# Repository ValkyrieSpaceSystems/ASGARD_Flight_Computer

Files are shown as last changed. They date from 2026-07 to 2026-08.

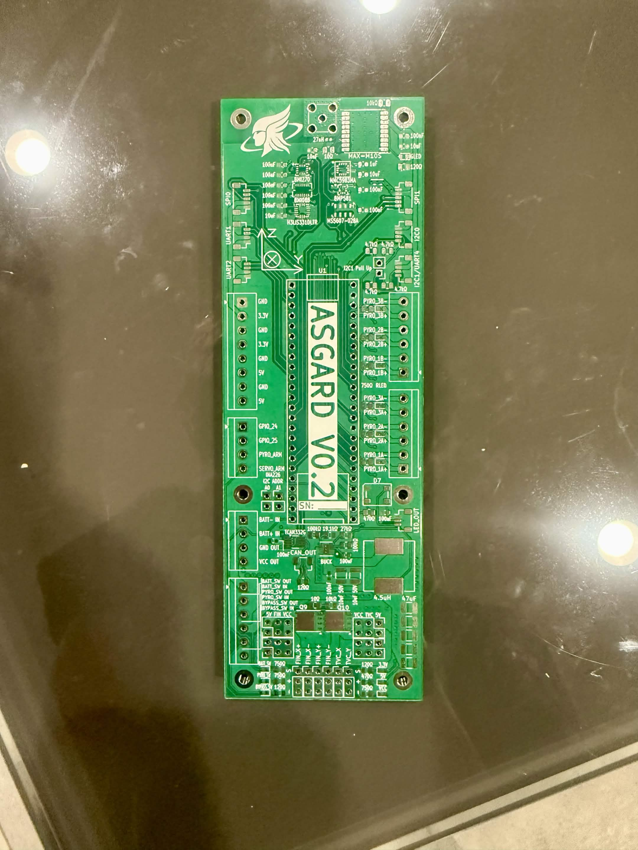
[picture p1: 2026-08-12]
V0.2 Front Picture (Not Assembled).png

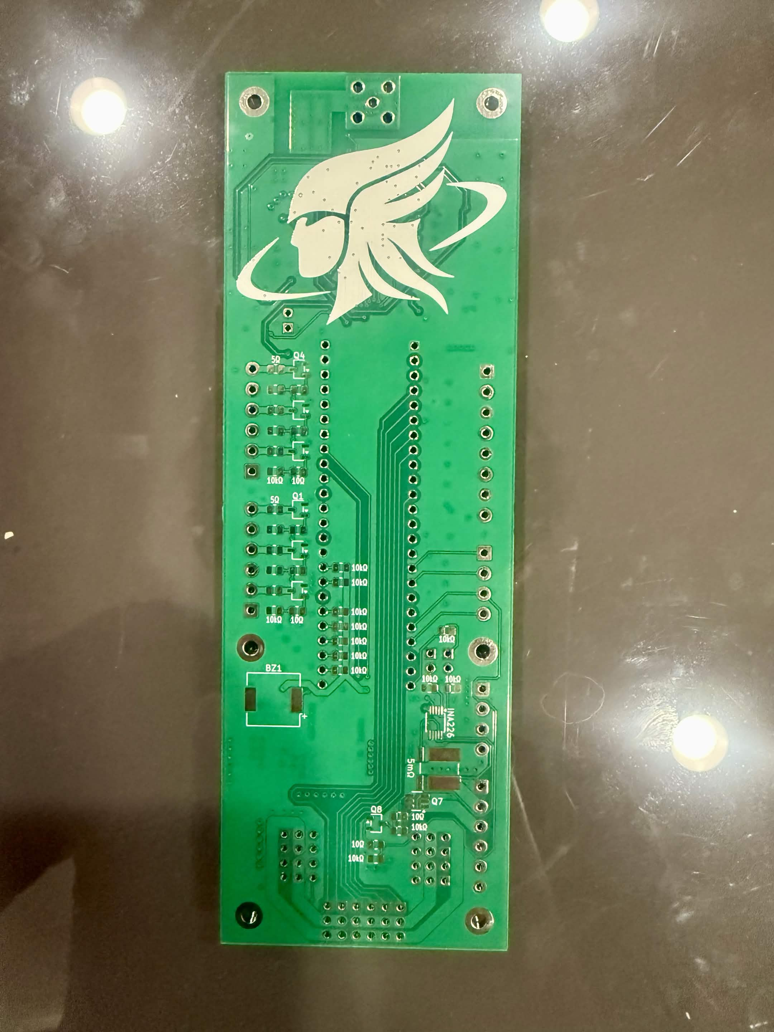
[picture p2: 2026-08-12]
V0.2 Back Picture (Not Assembled).png

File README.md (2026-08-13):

# Asgard Flight Computer

An open-source high power rocketry flight computer designed for long-term affordability through flexibility, modularity, and expandability. Designed to fly with [ODIN flight software](https://github.com/ValkyrieSpaceSystems/ODIN_Flight_Software) and communicate with the [Midgard ground station](https://github.com/ValkyrieSpaceSystems/MIDGARD_Ground_Control) over the [BIFROST protocol](https://github.com/ValkyrieSpaceSystems/BIFROST_Communications_Protocol).

---

## Sensors

| Component | Part | Interface |
|---|---|---|
| Low-altitude barometer | BMP581 | SPI |
| High-altitude barometer *(optional)* | MS5607 | SPI |
| Low-g IMU | BMI270 | SPI |
| Mid-g IMU | BMI088 | SPI |
| High-g accelerometer | H3LIS331DLTR | SPI |
| Magnetometer | MMC5983MA | SPI |
| GNSS | MAX-M10S | UART |
| Current monitor | INA226 | I2C |

---

## Pyrotechnics

3 independent events, 2 channels each (6 total). High-side arming via external switch keeps all channels unpowered until deliberately armed. Each channel has its own independent low-side MOSFET.

---

## Servo Control

6 outputs — a 4-channel group for fin deflection and a 2-channel group for thrust vector control. Each group is independently configurable via jumper to run from battery or regulated 5V.

---

## Communications

Interface agnostic — any physical transport (XBee, ELRS, RS-485, Bluetooth, CAN, USB, etc.) can carry BIFROST traffic with no firmware changes. A bypass switch port enables autonomous operation if ground station comms are unavailable.

---

## Expansion

2× SPI, 3× UART, 2× I2C, 1× CAN expansion ports, plus 2 GPIO breakout pins. Pyro arm and servo arm signals are also broken out for auxiliary boards.

**Current expansion boards:** RS-485, GPIO breakout

**Planned:** camera module, extra sensors, payload, multi-stage, Bluetooth/WiFi, high-power servos, pyro expansion

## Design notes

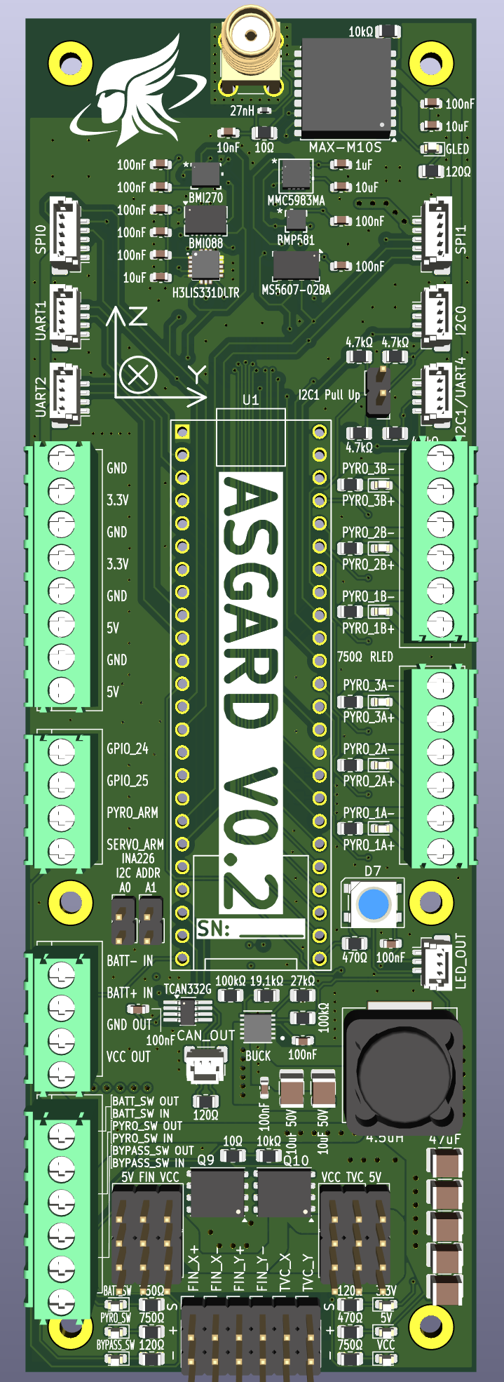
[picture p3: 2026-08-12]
V0.2 Front Render.png

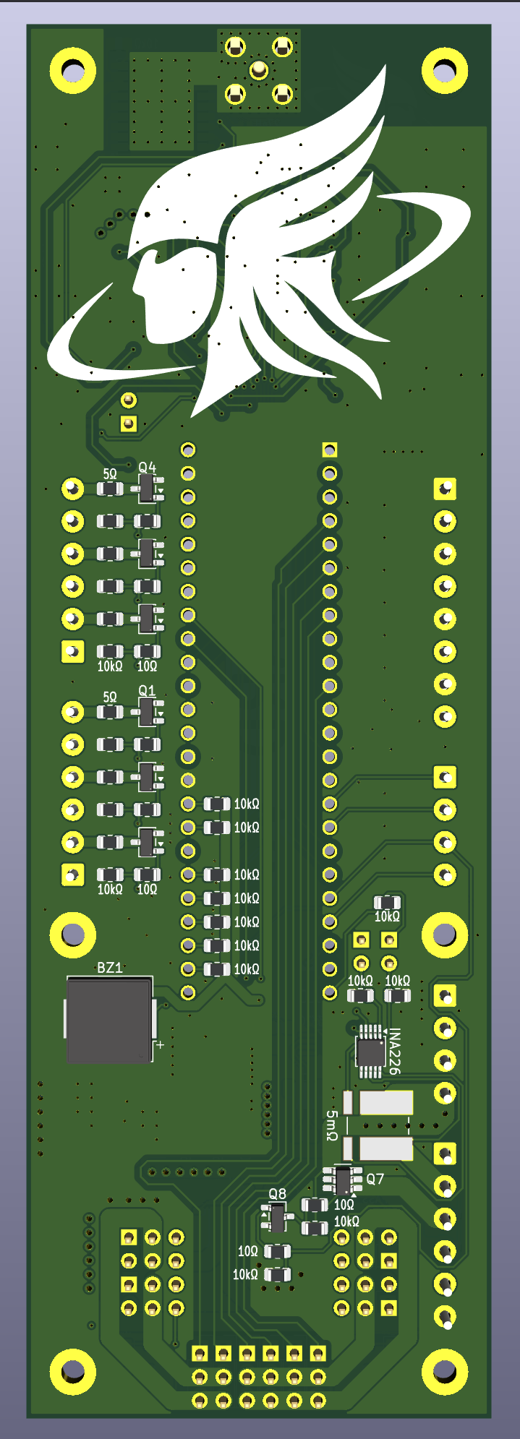
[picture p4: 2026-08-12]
V0.2 Back Render.png

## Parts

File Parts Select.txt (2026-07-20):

Low Altitude Barometer BMP581 (1)
	https://www.digikey.com/en/products/detail/bosch-sensortec/BMP581/16036134
	https://www.adafruit.com/product/6407
	https://www.sparkfun.com/sparkfun-micro-pressure-sensor-bmp581-qwiic.html
	https://github.com/adafruit/Adafruit_BMP5xx
	
High Altitude Barometer MS560702BA03-50 (1)
	https://www.digikey.com/en/products/detail/te-connectivity-measurement-specialties/MS560702BA03-50/4700931
	https://github.com/UravuLabs/MS5607

Low-G IMU BMI270 (1)
	https://www.digikey.com/en/products/detail/bosch-sensortec/BMI270/9974486
	https://www.sparkfun.com/sparkfun-6dof-imu-breakout-bmi270-qwiic.html
	https://github.com/sparkfun/SparkFun_BMI270_Arduino_Library

Mid-G IMU BMI088 (1)
	https://www.digikey.com/en/products/detail/bosch-sensortec/BMI088/8634936
	https://www.mouser.com/ProductDetail/Bosch-Sensortec/BMI088?qs=f9yNj16SXrIMFspTV6RB6Q%3D%3D
	https://github.com/AeroStrike/BMI088-Breakout-Board
	https://github.com/bolderflight/bmi088-arduino

High-G Accelerometer H3LIS331DLTR (1)
	https://www.digikey.com/en/products/detail/stmicroelectronics/H3LIS331DLTR/4311633
	https://www.adafruit.com/product/4627
	https://www.sparkfun.com/sparkfun-triple-axis-accelerometer-breakout-h3lis331dl.html
	https://github.com/sparkfun/SparkFun_LIS331_Arduino_Library

Magnetometer MMC5983MA (1)
	https://www.digikey.com/en/products/detail/memsic-inc/MMC5983MA/10452795
	https://www.sparkfun.com/sparkfun-micro-magnetometer-mmc5983ma-qwiic.html
	https://github.com/sparkfun/SparkFun_MMC5983MA_Magnetometer_Arduino_Library

Radio XBEE-PRO 900HP (1)
	https://www.tinyosshop.com/index.php?route=product/product&product_id=358
	https://www.digikey.com/en/products/detail/digi/XBP9B-DMST-002/3594157
	https://docs.digi.com//resources/documentation/digidocs/pdfs/90002474.pdf
	https://how2electronics.com/how-to-set-up-interface-xbee-module-with-arduino-tx-rx/
	https://learn.sparkfun.com/tutorials/exploring-xbees-and-xctu/all
	https://cse.google.com/cse?cx=008830049033802121810%3Azgsyidwem5w&q=xbee
	
Radio ELRS (1)

GNSS MAX-M10S-00B (1)
	https://www.digikey.com/en/products/detail/u-blox/MAX-M10S-00B/15712909
	https://www.sparkfun.com/sparkfun-gnss-receiver-breakout-max-m10s-qwiic.html
	https://github.com/sparkfun/SparkFun_u-blox_GNSS_v3
	https://content.u-blox.com/sites/default/files/MAX-M10S_IntegrationManual_UBX-20053088.pdf

Flash W25Q128JVSIQ TR (1)
	https://www.digikey.com/en/products/detail/winbond-electronics/W25Q128JVSIQ-TR/5803944
	https://www.hackster.io/news/adding-more-ram-and-flash-to-the-teensy-4-1-89e527855502
	https://github.com/PaulStoffregen/LittleFS
	
CANbus Transceiver TCAN332GDCNR (1)
	https://www.digikey.com/en/products/detail/texas-instruments/TCAN332GDCNR/6572320
	https://github.com/tonton81/FlexCAN_T4
	
5V Buck Converter LMR51460FSQDRRRQ1 (1)
	https://www.digikey.com/en/products/detail/texas-instruments/LMR51460FSQDRRRQ1/25318369
	
Current Monitor INA226AIDGSR (1)
	https://www.digikey.com/en/products/detail/texas-instruments/INA226AIDGSR/2687236
	https://github.com/RobTillaart/INA226

P-Channel MOSFET 6.9A SQ3419CEV-T1_GE3 (1)
	https://www.digikey.com/en/products/detail/vishay-siliconix/SQ3419CEV-T1-GE3/22080316
	https://www.adafruit.com/product/1794
N-Channel MOSFET 5A SI2318A-TP (6)
	https://www.digikey.com/en/products/detail/mcc-micro-commercial-components/SI2318A-TP/965103 mm5963
	https://www.adafruit.com/product/355
N-Channel MOSFET 17A BSC059N04LS6ATMA1 (2)
	https://www.digikey.com/en/products/detail/infineon-technologies/BSC059N04LS6ATMA1/9829538
NPN Transistor 2N3904 (1)
	https://www.digikey.com/en/products/detail/diotec-semiconductor/2N3904/13164701
	https://www.sparkfun.com/bag-o-transistors.html

 - Battery
 	-

Fingertech Mini Switch (3)
	https://www.csrocketry.com/electronics/altus-metrum/fingertech-mini-switch.html

E-Match Starter Kit
	https://www.apogeerockets.com/Rocket-Motors/Motor-Starters/E-match-Starter-Kit

SMA Connector (1)
	https://www.digikey.com/en/products/detail/adam-tech/RF2-04A-T-00-50-G/9830588

Battery Plugs XT60 (1M & 1F) FIT0587 (1)
	https://www.digikey.com/en/products/detail/dfrobot/FIT0587/9559256
	
1x2 Screw Terminal OSTTE020104 (17)
	https://www.digikey.com/en/products/detail/on-shore-technology-inc/OSTTE020104/2351816
	
Pin Headers (50M) (48F)
	2x3M (4) (Servo PWR/GND Select)
	1x3M (6) (Servos)
	1x2M (4) (I2C Jumpers)
	1x24F (2) (Teensy)
Pin Jumpers 0015381026 (11 max)
	https://www.digikey.com/en/products/detail/molex/0015381026/315124

JST SH 2 pin Connectors (1)
	https://www.digikey.com/en/products/detail/jst-sales-america-inc/BM02B-SRSS-TB/926694
JST SH 3 pin Connectors (1)
	https://www.digikey.com/en/products/detail/jst-sales-america-inc/BM03B-SRSS-TB/926695
JST SH 4 pin Connectors (10 pack) (4)
	https://www.adafruit.com/product/4328
	https://www.digikey.com/en/products/detail/jst-sales-america-inc/BM04B-SRSS-TB/926696
JST SH 5 pin Connectors (2)
	https://www.digikey.com/en/products/detail/jst-sales-america-inc/BM05B-SRSS-TB/926697
JST SH 8 pin Connectors (0)
	https://www.digikey.com/en/products/detail/jst-sales-america-inc/BM08B-SRSS-TB/926700

Buzzer CPT-9019A-SMT-TR (1)
	https://www.digikey.com/en/products/detail/same-sky-formerly-cui-devices/CPT-9019A-SMT-TR/19105220
NEOPIXEL (1)
	https://www.digikey.com/en/products/detail/w%C3%BCrth-elektronik/1315050930002/22677876
	https://www.adafruit.com/product/1655
	https://github.com/adafruit/Adafruit_NeoPixel
Red Indicator LEDs LTST-C191KRKT (6)
	https://www.digikey.com/en/products/detail/liteon/LTST-C191KRKT/386837
Green Indicator LEDs LTST-C191KGKT (1)
	https://www.digikey.com/en/products/detail/liteon/LTST-C191KGKT/386835
Orange Indicator LEDs LTST-C191KFKT (6)
	https://www.digikey.com/en/products/detail/liteon/LTST-C191KFKT/386833

5mΩ Shunt Resistor WSLP27265L000FEA (1)
	https://www.digikey.com/en/products/detail/vishay-dale/WSLP27265L000FEA/9751106
5Ω Resisotr ERJ-P06J5R1V (6)
	https://www.digikey.com/en/products/detail/panasonic-industry/ERJ-P06J5R1V/9812037
10Ω Resistor ERJ-P06J100V (10)
	https://www.digikey.com/en/products/detail/panasonic-industry/ERJ-P06J100V/525195
120Ω Resistor ERJ-P06J121V (4)
	https://www.digikey.com/en/products/detail/panasonic-industry/ERJ-P06J121V/525207
470Ω Resistor ERJ-P06J471V (2)
	https://www.digikey.com/en/products/detail/panasonic-industry/ERJ-P06J471V/525276
750Ω Resistor ERJ-P06J751V (9)
	https://www.digikey.com/en/products/detail/panasonic-industry/ERJ-P06J751V/525301
1kΩ Resistor ERJ-P06J102V (0)
	https://www.digikey.com/en/products/detail/panasonic-industry/ERJ-P06J102V/525197
4.7kΩ Resistor ERJ-P06J472V (4)
	https://www.digikey.com/en/products/detail/panasonic-industry/ERJ-P06J472V/525277
10kΩ Resistor ERJ-P06J103V (20)
	https://www.digikey.com/en/products/detail/panasonic-industry/ERJ-P06J103V/525198
19.1kΩ Resistor CRCW080519K1FKEAHP (1)
	https://www.digikey.com/en/products/detail/vishay-dale/CRCW080519K1FKEAHP/2227102
27kΩ Resistor ERJ-P06J273V (1)
	https://www.digikey.com/en/products/detail/panasonic-industry/ERJ-P06J273V/525249
100kΩ Resistor ERJ-P06J104V (2)
	https://www.digikey.com/en/products/detail/panasonic-industry/ERJ-P06J104V/525199

47pF 50V Capacitor CL10C470JB8NNNC (0)
	https://www.digikey.com/en/products/detail/samsung-electro-mechanics/CL10C470JB8NNNC/3886695
10nF 50V Capacitor C0603C103K5RACTU (1)
	https://www.digikey.com/en/products/detail/kemet/C0603C103K5RACTU/411090
100nF 50V Capacitor C1608X5R1H104K080AA (12)
	https://www.digikey.com/en/products/detail/tdk/C1608X5R1H104K080AA/2732891
1uF 16V Capacitor C0603C105K4RACTU (1)
	https://www.digikey.com/en/products/detail/kemet/C0603C105K4RACTU/2199788
10uF 25V Capacitor CL10A106MA8NRNC (3)
	https://www.digikey.com/en/products/detail/samsung-electro-mechanics/CL10A106MA8NRNC/3887527
10uF 50V Capapacitor C3225X7R1H106M250AC (2)
	https://www.digikey.com/en/products/detail/tdk/C3225X7R1H106M250AC/3952169
10uF 50V Polarized Capacitor 106CKH050MSA (0)
	https://www.digikey.com/en/products/detail/cornell-dubilier-knowles/106CKH050MSA/22188172
22uF 10V Capapacitor MSASL219LB5226MTNA01 (0)
	https://www.digikey.com/en/products/detail/taiyo-yuden/msasl219lb5226mtna01/16660989
47uF 16V Capacitor GRM32EC81C476KE15L (5)
	https://www.digikey.com/en/products/detail/murata-electronics/GRM32EC81C476KE15L/5027615

4.5uH Inductor SRR1208-4R5ML (1)
	https://www.digikey.com/en/products/detail/bourns-inc/SRR1208-4R5ML/2352894
27nH Inductor LQG15HS27NJ02D (1)
	https://www.digikey.com/en/products/detail/murata-electronics/LQG15HS27NJ02D/662877

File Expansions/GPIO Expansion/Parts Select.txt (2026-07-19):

GPIO Expander MCP23017T-E/SO (1)
	https://www.digikey.com/en/products/detail/microchip-technology/MCP23017T-E-SO/964184
	https://www.adafruit.com/product/5346
	https://github.com/adafruit/Adafruit-MCP23017-Arduino-Library

1x2 Screw Terminal OSTTE020104 (8)
	https://www.digikey.com/en/products/detail/on-shore-technology-inc/OSTTE020104/2351816
	
Pin Headers (6M)
	1x2M (3)
Pin Jumpers 0015381026 (3 max)
	https://www.digikey.com/en/products/detail/molex/0015381026/315124

JST SH 4 pin Connectors (10 pack) (2)
	https://www.adafruit.com/product/4328
	https://www.digikey.com/en/products/detail/jst-sales-america-inc/BM04B-SRSS-TB/926696

10kΩ Resistor ERJ-P06J103V (4)
	https://www.digikey.com/en/products/detail/panasonic-industry/ERJ-P06J103V/525198

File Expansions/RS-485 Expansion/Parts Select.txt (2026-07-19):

RS-485 Transceiver THVD1420DRLR (1)
	https://www.digikey.com/en/products/detail/texas-instruments/THVD1420DRLR/15856992

1x2 Screw Terminal OSTTE020104 (3)
	https://www.digikey.com/en/products/detail/on-shore-technology-inc/OSTTE020104/2351816
	
JST SH 4 pin Connectors (10 pack) (1)
	https://www.adafruit.com/product/4328
	https://www.digikey.com/en/products/detail/jst-sales-america-inc/BM04B-SRSS-TB/926696

RJ45 Connector (1)
	https://www.digikey.com/en/products/detail/abracon-llc/ARJM11D7-009-NN-EW2/7675212

120Ω Resistor ERJ-P06J121V (1)
	https://www.digikey.com/en/products/detail/panasonic-industry/ERJ-P06J121V/525207
750Ω Resistor ERJ-P06J751V (2)
	https://www.digikey.com/en/products/detail/panasonic-industry/ERJ-P06J751V/525301
10kΩ Resistor ERJ-P06J103V (2)
	https://www.digikey.com/en/products/detail/panasonic-industry/ERJ-P06J103V/525198

100nF 50V Capacitor C1608X5R1H104K080AA (2)
	https://www.digikey.com/en/products/detail/tdk/C1608X5R1H104K080AA/2732891

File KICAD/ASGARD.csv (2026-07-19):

Reference | Qty | Value | DNP | Exclude from BOM | Exclude from Board | Footprint | Datasheet
C1,C2 | 2 | 10uF 50V |  |  |  | Capacitor_SMD:C_1210_3225Metric
C3,C4,C10,C11,C12,C13,C14,C18,C19 | 9 | 100nF |  |  |  | Capacitor_SMD:C_0603_1608Metric
C5,C6,C7,C8,C9 | 5 | 47uF |  |  |  | Capacitor_SMD:C_1210_3225Metric
C15 | 1 | 10uF |  |  |  | Capacitor_THT:CP_Radial_D5.0mm_P2.00mm
C16 | 1 | 1uF |  |  |  | Capacitor_SMD:C_0603_1608Metric
C17,C20 | 2 | 10uF 25V |  |  |  | Capacitor_SMD:C_0603_1608Metric
C21 | 1 | 10nF |  |  |  | Capacitor_SMD:C_0603_1608Metric
C22 | 1 | 47pF |  |  |  | Capacitor_SMD:C_0603_1608Metric
D1,D2,D3,D4,D5,D6 | 6 | RLED |  |  |  | LED_SMD:LED_0603_1608Metric
D7 | 1 | NEOPIXEL |  |  |  | LED_SMD:LED_Inolux_IN-PI554FCH_PLCC4_5.0x5.0mm_P3.2mm | http://www.inolux-corp.com/datasheet/SMDLED/Addressable%20LED/IN-PI554FCH.pdf
D8,D9,D10,D11,D20 | 5 | GLED |  |  |  | LED_SMD:LED_0603_1608Metric
D17,D18,D19 | 3 | OLED |  |  |  | LED_SMD:LED_0603_1608Metric
J1 | 1 | BATT_TERM |  |  |  | TerminalBlock_4Ucon:TerminalBlock_4Ucon_1x04_P3.50mm_Horizontal
J2 | 1 | ARMING/GPIO |  |  |  | TerminalBlock_4Ucon:TerminalBlock_4Ucon_1x04_P3.50mm_Horizontal
J3 | 1 | PYRO_TERM_A |  |  |  | TerminalBlock_4Ucon:TerminalBlock_4Ucon_1x06_P3.50mm_Horizontal
J4 | 1 | PYRO_TERM_B |  |  |  | TerminalBlock_4Ucon:TerminalBlock_4Ucon_1x06_P3.50mm_Horizontal
J7 | 1 | SPI0 |  |  |  | Connector_JST:JST_SH_BM05B-SRSS-TB_1x05-1MP_P1.00mm_Vertical
J8 | 1 | SPI1 |  |  |  | Connector_JST:JST_SH_BM05B-SRSS-TB_1x05-1MP_P1.00mm_Vertical
J9 | 1 | CAN_OUT |  |  |  | Connector_JST:JST_SH_BM02B-SRSS-TB_1x02-1MP_P1.00mm_Vertical
J11 | 1 | SWITCH_TERM |  |  |  | TerminalBlock_4Ucon:TerminalBlock_4Ucon_1x06_P3.50mm_Horizontal
J12 | 1 | LED_OUT |  |  |  | Connector_JST:JST_SH_BM03B-SRSS-TB_1x03-1MP_P1.00mm_Vertical
J13 | 1 | UART1 |  |  |  | Connector_JST:JST_SH_BM04B-SRSS-TB_1x04-1MP_P1.00mm_Vertical
J14 | 1 | UART2 |  |  |  | Connector_JST:JST_SH_BM04B-SRSS-TB_1x04-1MP_P1.00mm_Vertical
J15 | 1 | CAN_IN |  |  |  | Connector_JST:JST_SH_BM02B-SRSS-TB_1x02-1MP_P1.00mm_Vertical
J16 | 1 | UART3 |  |  |  | Connector_JST:JST_SH_BM04B-SRSS-TB_1x04-1MP_P1.00mm_Vertical
J17 | 1 | SMA |  |  |  | Connector_Coaxial:SMA_Amphenol_132134-11_Vertical
J18 | 1 | I2C0 |  |  |  | Connector_JST:JST_SH_BM04B-SRSS-TB_1x04-1MP_P1.00mm_Vertical
J19 | 1 | 5V |  |  |  | TerminalBlock_4Ucon:TerminalBlock_4Ucon_1x04_P3.50mm_Horizontal
J21 | 1 | I2C1/UART4 |  |  |  | Connector_JST:JST_SH_BM04B-SRSS-TB_1x04-1MP_P1.00mm_Vertical
J22 | 1 | 3.3V |  |  |  | TerminalBlock_4Ucon:TerminalBlock_4Ucon_1x04_P3.50mm_Horizontal
J23 | 1 | UART5 |  |  |  | Connector_JST:JST_SH_BM04B-SRSS-TB_1x04-1MP_P1.00mm_Vertical
JP3 | 1 | I2C1 Pull Up |  |  |  | Connector_PinHeader_2.54mm:PinHeader_1x02_P2.54mm_Vertical
JP4,JP5 | 2 | Jumper_2_Open |  |  |  | Connector_PinHeader_2.54mm:PinHeader_1x02_P2.54mm_Vertical
L1 | 1 | 4.5uH |  |  |  | SRR1208-120ML:IND_SRR1208-120ML
L2 | 1 | 27nH |  |  |  | Inductor_SMD:L_0402_1005Metric
M1 | 1 | FIN_X+ |  |  |  | Connector_PinHeader_2.54mm:PinHeader_1x03_P2.54mm_Vertical | http://forums.parallax.com/uploads/attachments/46831/74481.png
M2 | 1 | FIN_X- |  |  |  | Connector_PinHeader_2.54mm:PinHeader_1x03_P2.54mm_Vertical | http://forums.parallax.com/uploads/attachments/46831/74481.png
M3 | 1 | FIN_Y+ |  |  |  | Connector_PinHeader_2.54mm:PinHeader_1x03_P2.54mm_Vertical | http://forums.parallax.com/uploads/attachments/46831/74481.png
M4 | 1 | FIN_Y- |  |  |  | Connector_PinHeader_2.54mm:PinHeader_1x03_P2.54mm_Vertical | http://forums.parallax.com/uploads/attachments/46831/74481.png
M5 | 1 | TVC_X |  |  |  | Connector_PinHeader_2.54mm:PinHeader_1x03_P2.54mm_Vertical | http://forums.parallax.com/uploads/attachments/46831/74481.png
M6 | 1 | TVC_Y |  |  |  | Connector_PinHeader_2.54mm:PinHeader_1x03_P2.54mm_Vertical | http://forums.parallax.com/uploads/attachments/46831/74481.png
Q1 | 1 | DROGUE_MOSFET_A |  |  |  | Package_TO_SOT_SMD:SOT-23-3
Q2 | 1 | MAIN_MOSFET_A |  |  |  | Package_TO_SOT_SMD:SOT-23-3
Q3 | 1 | MOTOR_MOSFET_A |  |  |  | Package_TO_SOT_SMD:SOT-23-3
Q4 | 1 | DROGUE_MOSFET_B |  |  |  | Package_TO_SOT_SMD:SOT-23-3
Q5 | 1 | MAIN_MOSFET_B |  |  |  | Package_TO_SOT_SMD:SOT-23-3
Q6 | 1 | MOTOR_MOSFET_B |  |  |  | Package_TO_SOT_SMD:SOT-23-3
Q7 | 1 | PYRO_ARM_MOSFET |  |  |  | Package_TO_SOT_SMD:SOT-23-6_Handsoldering
Q8 | 1 | PYRO_ARM_TRANS |  |  |  | Package_TO_SOT_SMD:SOT-23-3
Q9 | 1 | 5V_SERVO_ARM_MOSFET |  |  |  | Package_SON:Infineon_PG-TDSON-8_6.15x5.15mm
Q10 | 1 | VCC_SERVO_ARM_MOSFET |  |  |  | Package_SON:Infineon_PG-TDSON-8_6.15x5.15mm
R1 | 1 | 5mΩ |  |  |  | WSLP:RES_WSLP2726L2000FEA
R5,R7,R15,R18,R19,R20 | 6 | 750Ω |  |  |  | Resistor_SMD:R_0805_2012Metric
R12,R26,R27,R28,R38,R41,R43,R45,R47,R49,R52,R71,R72,R77 | 14 | 10kΩ |  |  |  | Resistor_SMD:R_0805_2012Metric
R13,R14,R16,R17,R21,R22,R59,R60,R61,R78 | 10 | 120Ω |  |  |  | Resistor_SMD:R_0805_2012Metric
R23,R24,R25,R33,R40,R42,R44,R46,R48,R53 | 10 | 10Ω |  |  |  | Resistor_SMD:R_0805_2012Metric
R29,R30,R31,R73,R74,R75 | 6 | 5Ω |  |  |  | Resistor_SMD:R_0805_2012Metric
R34,R35,R50,R51 | 4 | 4.7kΩ |  |  |  | Resistor_SMD:R_0805_2012Metric
R39 | 1 | 470Ω |  |  |  | Resistor_SMD:R_0805_2012Metric
R67,R69 | 2 | 100kΩ |  |  |  | Resistor_SMD:R_0805_2012Metric
R68 | 1 | 27kΩ |  |  |  | Resistor_SMD:R_0805_2012Metric
R70 | 1 | 19.1kΩ |  |  |  | Resistor_SMD:R_0805_2012Metric
TP1,TP5 | 2 | GND |  |  |  | TestPoint:TestPoint_Loop_D2.60mm_Drill1.6mm_Beaded
TP2 | 1 | 3.3V |  |  |  | TestPoint:TestPoint_Loop_D2.60mm_Drill1.6mm_Beaded
TP3 | 1 | 5V |  |  |  | TestPoint:TestPoint_Loop_D2.60mm_Drill1.6mm_Beaded
TP4 | 1 | VCC |  |  |  | TestPoint:TestPoint_Loop_D2.60mm_Drill1.6mm_Beaded
TP6,TP7,TP8,TP9,TP10,TP11,TP12 | 7 | TestPoint |  |  |  | TestPoint:TestPoint_Loop_D2.60mm_Drill1.6mm_Beaded
U1 | 1 | Teensy4.1 |  |  |  | Teensy:Teensy41
U2 | 1 | INA226 |  |  |  | Package_SO:TSSOP-10_3x3mm_P0.5mm | http://www.ti.com/lit/ds/symlink/ina226.pdf
U3 | 1 | LMR51460SQDRRRQ1 |  |  |  | LMR51460SQDRRRQ1:DRR0012E-IPC_A | https://www.ti.com/lit/gpn/lmr51460-q1
U4 | 1 | BMI088 |  |  |  | Package_LGA:Bosch_LGA-16_4.5x3mm_P0.5mm_LayoutBorder7x1y_ClockwisePinNumbering | https://www.bosch-sensortec.com/media/boschsensortec/downloads/datasheets/bst-bmi088-ds001.pdf
U5 | 1 | H3LIS331DLTR |  |  |  | H3LIS331DLTR:QFN300X300X100-16N
U6 | 1 | BMP581 |  |  |  | BMP581:QFN10_BMP581_BOS | BMP581
U7 | 1 | MMC5983MA |  |  |  | MMC5983MA:MMC5983MA_MEM | MMC5983MA
U8 | 1 | MAX-M10S |  |  |  | RF_GPS:ublox_MAX | https://content.u-blox.com/sites/default/files/MAX-M10S_DataSheet_UBX-20035208.pdf
U9 | 1 | TCAN332G |  |  |  | Package_TO_SOT_SMD:TSOT-23-8_HandSoldering | http://www.ti.com/lit/ds/symlink/tcan337.pdf

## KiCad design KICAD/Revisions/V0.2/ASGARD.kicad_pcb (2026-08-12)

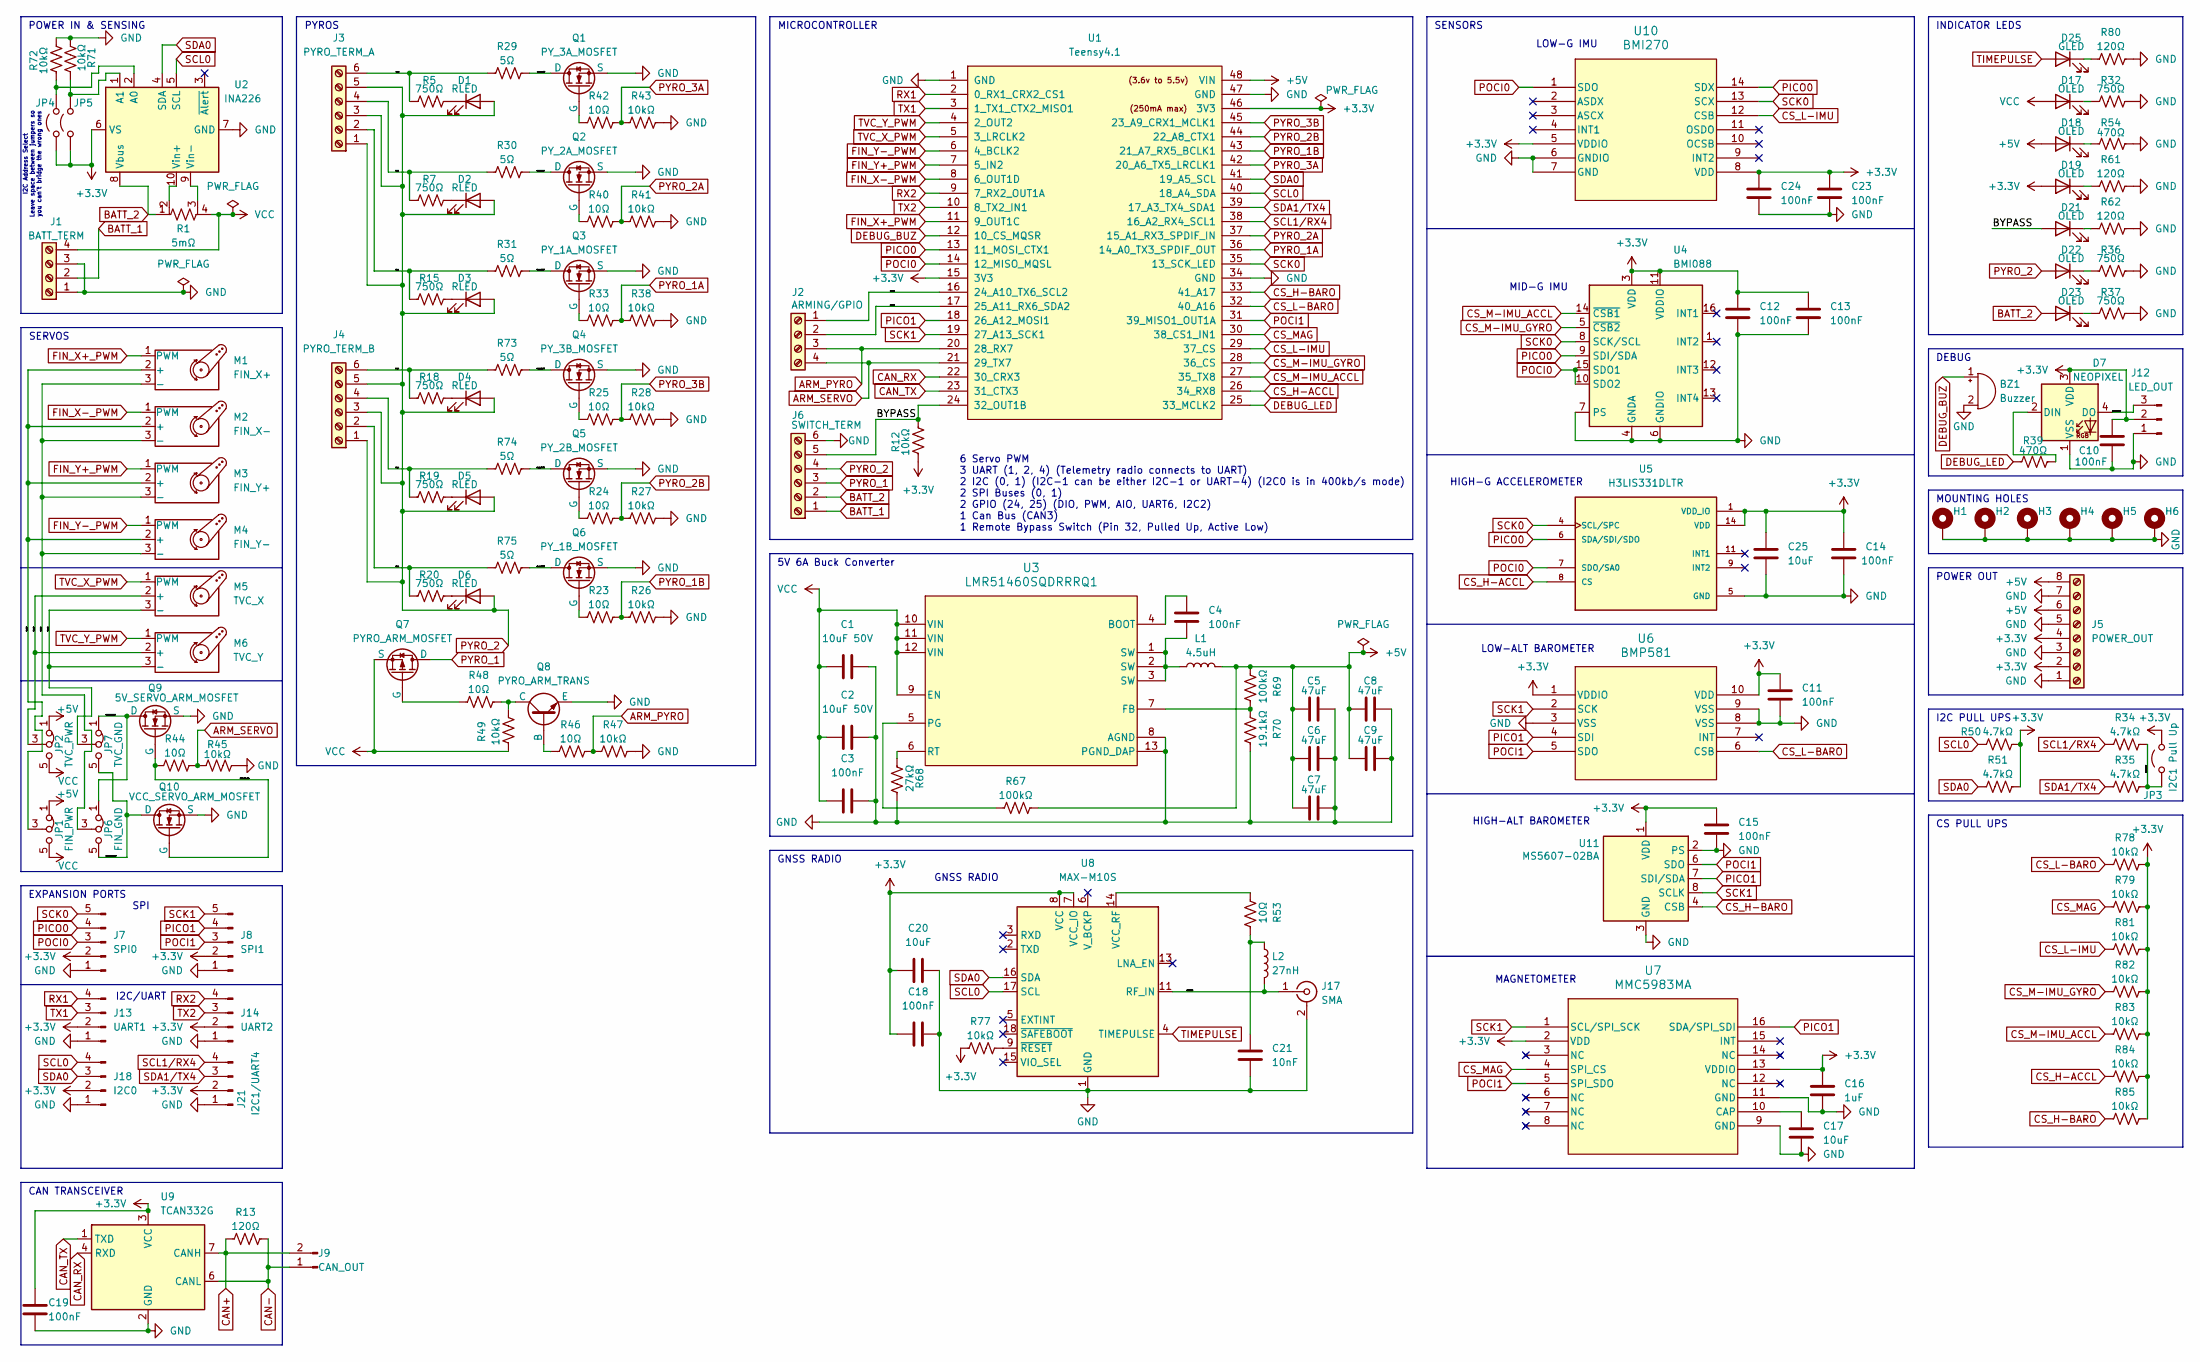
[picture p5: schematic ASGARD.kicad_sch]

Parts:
BZ1: Buzzer; Buzzer_CUI_CPT-9019S-SMT
C1, C2: 10uF 50V; C_1210_3225Metric
C3, C4, C10, C11, C12, C13, C14, C15, C18, C19, C23, C24: 100nF; C_0603_1608Metric
C5, C6, C7, C8, C9: 47uF; C_1210_3225Metric
C16: 1uF; C_0603_1608Metric
C17, C20, C25: 10uF; C_0603_1608Metric
C21: 10nF; C_0603_1608Metric
D1, D2, D3, D4, D5, D6: RLED; LED_0603_1608Metric
D7: NEOPIXEL; LED_Inolux_IN-PI554FCH_PLCC4_5.0x5.0mm_P3.2mm
D17, D18, D19, D21, D22, D23: OLED; LED_0603_1608Metric
D25: GLED; LED_0603_1608Metric
H1, H2, H3, H4, H5, H6: MountingHole_Pad; MountingHole_2.5mm_Pad
J1: BATT_TERM; TerminalBlock_4Ucon_1x04_P3.50mm_Horizontal
J2: ARMING/GPIO; TerminalBlock_4Ucon_1x04_P3.50mm_Horizontal
J3: PYRO_TERM_A; TerminalBlock_4Ucon_1x06_P3.50mm_Horizontal
J4: PYRO_TERM_B; TerminalBlock_4Ucon_1x06_P3.50mm_Horizontal
J5: POWER_OUT; TerminalBlock_4Ucon_1x08_P3.50mm_Horizontal
J6: SWITCH_TERM; TerminalBlock_4Ucon_1x06_P3.50mm_Horizontal
J7: SPI0; JST_SH_BM05B-SRSS-TB_1x05-1MP_P1.00mm_Vertical
J8: SPI1; JST_SH_BM05B-SRSS-TB_1x05-1MP_P1.00mm_Vertical
J9: CAN_OUT; JST_SH_BM02B-SRSS-TB_1x02-1MP_P1.00mm_Vertical
J12: LED_OUT; JST_SH_BM03B-SRSS-TB_1x03-1MP_P1.00mm_Vertical
J13: UART1; JST_SH_BM04B-SRSS-TB_1x04-1MP_P1.00mm_Vertical
J14: UART2; JST_SH_BM04B-SRSS-TB_1x04-1MP_P1.00mm_Vertical
J17: SMA; SMA_Amphenol_132134-11_Vertical
J18: I2C0; JST_SH_BM04B-SRSS-TB_1x04-1MP_P1.00mm_Vertical
J21: I2C1/UART4; JST_SH_BM04B-SRSS-TB_1x04-1MP_P1.00mm_Vertical
JP1: FIN_PWR; PinHeader_2x03_P2.54mm_Vertical
JP2: TVC_PWR; PinHeader_2x03_P2.54mm_Vertical
JP3: I2C1 Pull Up; PinHeader_1x02_P2.54mm_Vertical
JP4, JP5: Jumper_2_Open; PinHeader_1x02_P2.54mm_Vertical
JP6: FIN_GND; PinHeader_2x03_P2.54mm_Vertical
JP7: TVC_GND; PinHeader_2x03_P2.54mm_Vertical
L1: 4.5uH; IND_SRR1208-120ML
L2: 27nH; L_0402_1005Metric
M1: FIN_X+; PinHeader_1x03_P2.54mm_Vertical
M2: FIN_X-; PinHeader_1x03_P2.54mm_Vertical
M3: FIN_Y+; PinHeader_1x03_P2.54mm_Vertical
M4: FIN_Y-; PinHeader_1x03_P2.54mm_Vertical
M5: TVC_X; PinHeader_1x03_P2.54mm_Vertical
M6: TVC_Y; PinHeader_1x03_P2.54mm_Vertical
Q1: PY_3A_MOSFET; SOT-23-3
Q2: PY_2A_MOSFET; SOT-23-3
Q3: PY_1A_MOSFET; SOT-23-3
Q4: PY_3B_MOSFET; SOT-23-3
Q5: PY_2B_MOSFET; SOT-23-3
Q6: PY_1B_MOSFET; SOT-23-3
Q7: PYRO_ARM_MOSFET; SOT-23-6_Handsoldering
Q8: PYRO_ARM_TRANS; SOT-23-3
Q9: 5V_SERVO_ARM_MOSFET; Infineon_PG-TDSON-8_6.15x5.15mm
Q10: VCC_SERVO_ARM_MOSFET; Infineon_PG-TDSON-8_6.15x5.15mm
R1: 5mΩ; RES_WSLP2726L2000FEA
R5, R7, R15, R18, R19, R20, R32, R36, R37: 750Ω; R_0805_2012Metric
R12, R26, R27, R28, R38, R41, R43, R45, R47, R49, R71, R72, R77, R78, R79, R81, R82, R83, R84, R85: 10kΩ; R_0805_2012Metric
R13, R61, R62, R80: 120Ω; R_0805_2012Metric
R23, R24, R25, R33, R40, R42, R44, R46, R48, R53: 10Ω; R_0805_2012Metric
R29, R30, R31, R73, R74, R75: 5Ω; R_0805_2012Metric
R34, R35, R50, R51: 4.7kΩ; R_0805_2012Metric
R39, R54: 470Ω; R_0805_2012Metric
R67, R69: 100kΩ; R_0805_2012Metric
R68: 27kΩ; R_0805_2012Metric
R70: 19.1kΩ; R_0805_2012Metric
U1: Teensy4.1; Teensy41
U2: INA226; TSSOP-10_3x3mm_P0.5mm
U3: LMR51460SQDRRRQ1; DRR0012E-IPC_A
U4: BMI088; Bosch_LGA-16_4.5x3mm_P0.5mm_LayoutBorder7x1y_ClockwisePinNu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
U5: H3LIS331DLTR; QFN300X300X100-16N
U6: BMP581; QFN10_BMP581_BOS
U7: MMC5983MA; MMC5983MA_MEM
U8: MAX-M10S; ublox_MAX
U9: TCAN332G; TSOT-23-8_HandSoldering
U10: BMI270; BMI270_BOS
U11: MS5607-02BA; LGA-8_3x5mm_P1.25mm

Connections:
+3.3V: C10.2, C11.2, C12.1, C13.2, C14.2, C15.2, C16.1, C18.2, C19.1, C20.1, C23.1, C24.2, C25.1, D7.3 (VDD), D19.2 (A), J5.2, J5.4, J7.2, J8.2, J12.2, J13.2, J14.2, J18.2, J21.2, JP3.2 (B), JP4.1 (A), JP5.1 (A), R12.1, R50.2, R51.2, R77.1, R78.2, R79.2, R81.2, R82.2, R83.2, R84.2, R85.2, U1.15 (3V3), U1.46 (3V3), U2.6 (VS), U4.3 (VDD), U4.11 (VDDIO), U5.1 (VDD_IO), U5.14 (VDD), U5.15 (VDD), U6.1 (VDDIO), U6.10 (VDD), U7.2 (VDD), U7.13 (VDDIO), U8.7 (VCC_IO), U8.8 (VCC), U9.3 (VCC), U10.5 (VDDIO), U10.8 (VDD), U11.1 (VDD)
+5V: C5.2, C6.2, C7.2, C8.2, C9.2, D18.2 (A), J5.6, J5.8, JP1.1 (A), JP2.1 (A), L1.2, R67.2, R69.1, U1.48 (VIN)
/5V_SERVO_MOSFET: JP6.1 (A), JP7.1 (A), Q9.5 (D)
/BYPASS: D21.2 (A), J6.5, R12.2, U1.24 (32_OUT1B)
/DEBUG_LED_OUT: D7.4 (DO), J12.3
/FIN_GND: JP6.3 (C), M1.3 (-), M2.3 (-), M3.3 (-), M4.3 (-)
/FIN_PWR: JP1.3 (C), M1.2 (+), M2.2 (+), M3.2 (+), M4.2 (+)
/GPIO_24: J2.1, U1.16 (24_A10_TX6_SCL2)
/GPIO_25: J2.2, U1.17 (25_A11_RX6_SDA2)
/I2C1_PULL_UP: JP3.1 (A), R34.2, R35.2
/MICROSTRIP: J17.1 (In), L2.2, U8.11 (RF_IN)
/PY_1A: J3.2, R15.1, R31.1
/PY_1A_MOSFET: Q3.3 (D), R31.2
/PY_1B: J4.2, R20.1, R75.1
/PY_1B_MOSFET: Q6.3 (D), R75.2
/PY_2A: J3.4, R7.1, R30.1
/PY_2A_MOSFET: Q2.3 (D), R30.2
/PY_2B: J4.4, R19.1, R74.1
/PY_2B_MOSFET: Q5.3 (D), R74.2
/PY_3A: J3.6, R5.1, R29.1
/PY_3A_MOSFET: Q1.3 (D), R29.2
/PY_3B: J4.6, R18.1, R73.1
/PY_3B_MOSFET: Q4.3 (D), R73.2
/SERVO_ARM_GATE: Q9.4 (G), Q10.4 (G), R44.1
/TVC_GND: JP7.3 (C), M5.3 (-), M6.3 (-)
/TVC_PWR: JP2.3 (C), M5.2 (+), M6.2 (+)
/VCC_SERVO_MOSFET: JP6.5 (B), JP7.5 (B), Q10.5 (D)
ARM_PYRO: J2.3, R46.2, R47.1, U1.20 (28_RX7)
ARM_SERVO: J2.4, R44.2, R45.1, U1.21 (29_TX7)
BATT_1: J1.2, J6.1
BATT_2: D23.2 (A), J6.2, R1.1, U2.8 (Vbus)
CAN+: J9.2, R13.1, U9.7 (CANH)
CAN-: J9.1, R13.2, U9.6 (CANL)
CAN_RX: U1.22 (30_CRX3), U9.4 (RXD)
CAN_TX: U1.23 (31_CTX3), U9.1 (TXD)
CS_H-ACCL: R84.1, U1.26 (34_RX8), U5.8 (CS)
CS_H-BARO: R85.1, U1.33 (41_A17), U11.4 (CSB), U11.5 (CSB)
CS_L-BARO: R78.1, U1.32 (40_A16), U6.6 (CSB)
CS_L-IMU: R81.1, U1.29 (37_CS), U10.12 (CSB)
CS_M-IMU_ACCL: R83.1, U1.27 (35_TX8), U4.14 (~CSB1)
CS_M-IMU_GYRO: R82.1, U1.28 (36_CS), U4.5 (~CSB2)
CS_MAG: R79.1, U1.30 (38_CS1_IN1), U7.4 (SPI_CS)
DEBUG_BUZ: BZ1.1 (+), U1.12 (10_CS_MQSR)
DEBUG_LED: R39.1, U1.25 (33_MCLK2)
FIN_X+_PWM: M1.1 (PWM), U1.11 (9_OUT1C)
FIN_X-_PWM: M2.1 (PWM), U1.8 (6_OUT1D)
FIN_Y+_PWM: M3.1 (PWM), U1.7 (5_IN2)
FIN_Y-_PWM: M4.1 (PWM), U1.6 (4_BCLK2)
GND: BZ1.2 (-), C1.2, C2.2, C3.2, C5.1, C6.1, C7.1, C8.1, C9.1, C10.1, C11.1, C12.2, C13.1, C14.1, C15.1, C16.2, C17.2, C18.1, C19.2, C20.2, C21.2, C23.2, C24.1, C25.2, D7.1 (VSS), H1.1 (1_1), H2.1 (1_1), H3.1 (1_1), H4.1 (1_1), H5.1 (1_1), H6.1 (1_1), J1.1, J1.3, J5.1, J5.3, J5.5, J5.7, J6.6, J7.1, J8.1, J12.1, J13.1, J14.1, J17.2 (Ext), J18.1, J21.1, Q1.2 (S), Q2.2 (S), Q3.2 (S), Q4.2 (S), Q5.2 (S), Q6.2 (S), Q8.2 (E), Q9.1 (S), Q10.1 (S), R26.2, R27.2, R28.2, R32.2, R36.2, R37.2, R38.2, R41.2, R43.2, R45.2, R47.2, R54.2, R61.2, R62.2, R68.2, R70.2, R71.1, R72.2, R80.2, U1.1 (GND), U1.34 (GND), U1.47 (GND), U2.7 (GND), U3.8 (AGND), U3.13 (PGND_DAP), U4.2 (GNDA), U4.4 (GNDA), U4.6 (GNDIO), U4.7 (PS), U5.5 (GND), U5.10 (GND), U5.12 (GND), U5.13 (GND), U5.16 (GND), U6.3 (VSS), U6.8 (VSS), U6.9 (VSS), U7.9 (GND), U7.11 (GND), U8.1 (GND), U8.10 (GND), U8.12 (GND), U9.2 (GND), U10.6 (GNDIO), U10.7 (GND), U11.2 (PS), U11.3 (GND)
unnamed: C4.2, L1.1, U3.1 (SW), U3.2 (SW), U3.3 (SW)
unnamed: C21.1, L2.1, R53.2
unnamed: D1.1 (K), R5.2
unnamed: D2.1 (K), R7.2
unnamed: D3.1 (K), R15.2
unnamed: D4.1 (K), R18.2
unnamed: D5.1 (K), R19.2
unnamed: D6.1 (K), R20.2
unnamed: D7.2 (DIN), R39.2
unnamed: D17.1 (K), R32.1
unnamed: D18.1 (K), R54.1
unnamed: D19.1 (K), R61.1
unnamed: D21.1 (K), R62.1
unnamed: D22.1 (K), R36.1
unnamed: D23.1 (K), R37.1
unnamed: D25.1 (K), R80.1
unnamed: JP4.2 (B), R72.1, U2.2 (A0)
unnamed: JP5.2 (B), R71.2, U2.1 (A1)
unnamed: Q1.1 (G), R42.1
unnamed: Q2.1 (G), R40.1
unnamed: Q3.1 (G), R33.1
unnamed: Q4.1 (G), R25.1
unnamed: Q5.1 (G), R24.1
unnamed: Q6.1 (G), R23.1
unnamed: Q7.3 (G), R48.1
unnamed: Q8.1 (B), R46.1
unnamed: Q8.3 (C), R48.2, R49.2
unnamed: R1.2, U2.10 (Vin+)
unnamed: R1.3, U2.9 (Vin-)
unnamed: C4.1, U3.4 (BOOT)
unnamed: R69.2, R70.1, U3.7 (FB)
unnamed: R67.1, U3.5 (PG)
unnamed: R68.1, U3.6 (RT)
unnamed: C17.1, U7.10 (CAP)
unnamed: R53.1, U8.14 (VCC_RF)
unnamed: R77.2, U8.9 (~RESET)
PICO0: J7.4, U1.13 (11_MOSI_CTX1), U4.9 (SDI/SDA), U5.6 (SDA/SDI/SDO), U10.14 (SDX)
PICO1: J8.4, U1.18 (26_A12_MOSI1), U6.4 (SDI), U7.16 (SDA/SPI_SDI), U11.7 (SDI/SDA)
POCI0: J7.3, U1.14 (12_MISO_MQSL), U4.10 (SDO2), U4.15 (SDO1), U5.7 (SDO/SA0), U10.1 (SDO)
POCI1: J8.3, U1.31 (39_MISO1_OUT1A), U6.5 (SDO), U7.5 (SPI_SDO), U11.6 (SDO)
PYRO_1: J6.3, Q7.1 (D)
PYRO_1A: R33.2, R38.1, U1.36 (14_A0_TX3_SPDIF_OUT)
PYRO_1B: R23.2, R26.1, U1.43 (21_A7_RX5_BCLK1)
PYRO_2: D1.2 (A), D2.2 (A), D3.2 (A), D4.2 (A), D5.2 (A), D6.2 (A), D22.2 (A), J3.1, J3.3, J3.5, J4.1, J4.3, J4.5, J6.4
PYRO_2A: R40.2, R41.1, U1.37 (15_A1_RX3_SPDIF_IN)
PYRO_2B: R24.2, R27.1, U1.44 (22_A8_CTX1)
PYRO_3A: R42.2, R43.1, U1.42 (20_A6_TX5_LRCLK1)
PYRO_3B: R25.2, R28.1, U1.45 (23_A9_CRX1_MCLK1)
RX1: J13.4, U1.2 (0_RX1_CRX2_CS1)
RX2: J14.4, U1.9 (7_RX2_OUT1A)
SCK0: J7.5, U1.35 (13_SCK_LED), U4.8 (SCK/SCL), U5.4 (SCL/SPC), U10.13 (SCX)
SCK1: J8.5, U1.19 (27_A13_SCK1), U6.2 (SCK), U7.1 (SCL/SPI_SCK), U11.8 (SCLK)
SCL0: J18.4, R50.1, U1.40 (18_A4_SDA), U2.5 (SCL), U8.17 (SCL)
SCL1/RX4: J21.4, R34.1, U1.38 (16_A2_RX4_SCL1)
SDA0: J18.3, R51.1, U1.41 (19_A5_SCL), U2.4 (SDA), U8.16 (SDA)
SDA1/TX4: J21.3, R35.1, U1.39 (17_A3_TX4_SDA1)
TIMEPULSE: D25.2 (A), U8.4 (TIMEPULSE)
TVC_X_PWM: M5.1 (PWM), U1.5 (3_LRCLK2)
TVC_Y_PWM: M6.1 (PWM), U1.4 (2_OUT2)
TX1: J13.3, U1.3 (1_TX1_CTX2_MISO1)
TX2: J14.3, U1.10 (8_TX2_IN1)
VCC: C1.1, C2.1, C3.1, D17.2 (A), J1.4, JP1.5 (B), JP2.5 (B), Q7.4 (S), R1.4, R49.1, U3.9 (EN), U3.10 (VIN), U3.11 (VIN), U3.12 (VIN)

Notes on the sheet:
MICROCONTROLLER
5V 6A Buck Converter
CS PULL UPS
HIGH-G ACCELEROMETER
MAGNETOMETER
DEBUG
I2C Address Select Leave space between jumpers so you can't bridge the wrong ones
I2C/UART
SERVOS
LOW-G IMU
INDICATOR LEDS
I2C PULL UPS
MOUNTING HOLES
POWER IN & SENSING
SENSORS
PYROS
GNSS RADIO
HIGH-ALT BAROMETER
6 Servo PWM 3 UART (1, 2, 4) (Telemetry radio connects to UART) 2 I2C (0, 1) (I2C-1 can be either I2C-1 or UART-4) (I2C0 is in 400kb/s mode) 2 SPI Buses (0, 1) 2 GPIO (24, 25) (DIO, PWM, AIO, UART6, I2C2) 1 Can Bus (CAN3) 1 Remote Bypass Switch (Pin 32, Pulled Up, Active Low)
POWER OUT
SPI
EXPANSION PORTS
LOW-ALT BAROMETER
MID-G IMU
CAN TRANSCEIVER

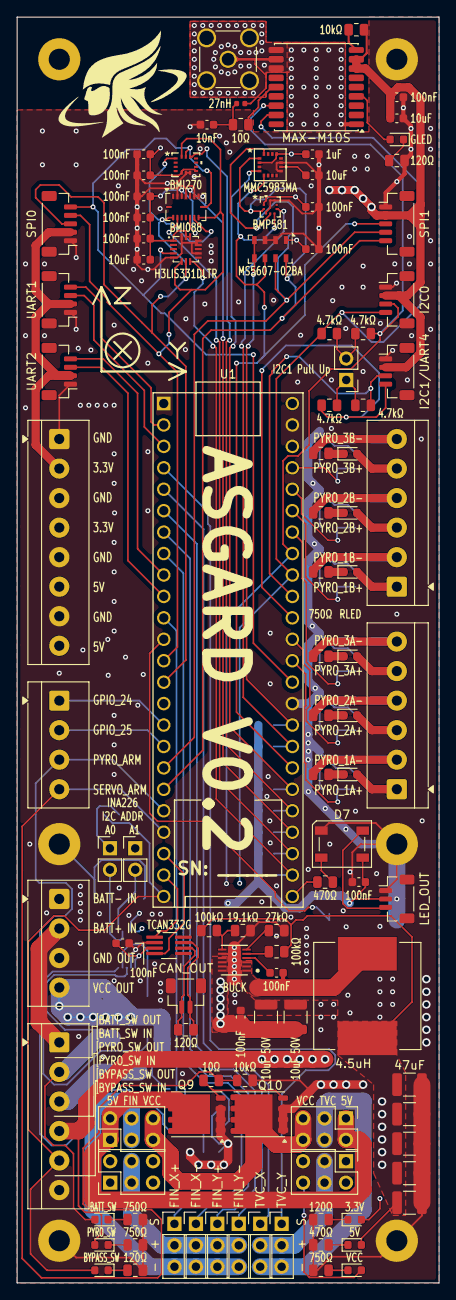
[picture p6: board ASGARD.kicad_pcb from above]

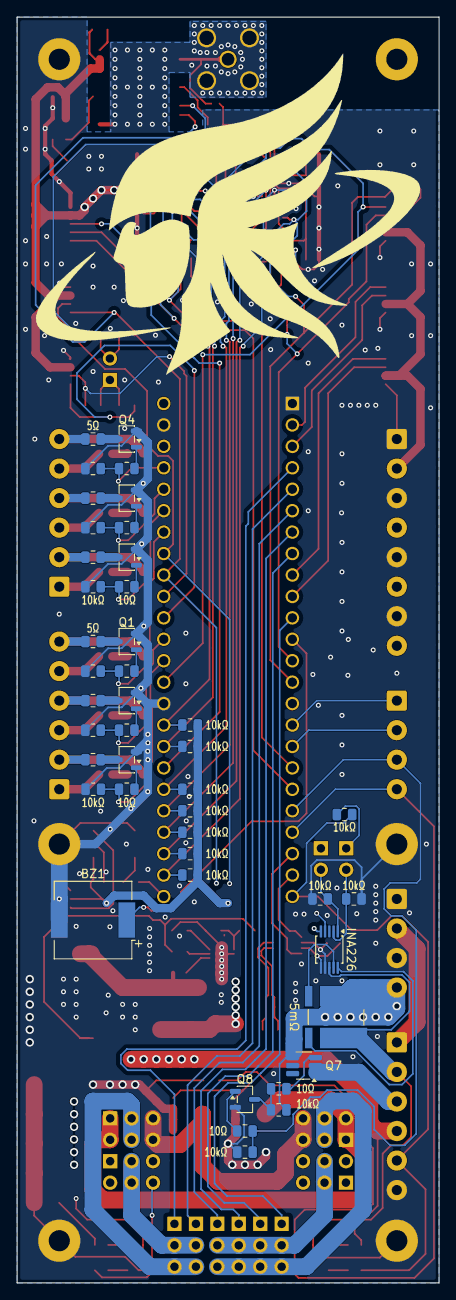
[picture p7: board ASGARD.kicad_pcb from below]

Board: 4 copper layers, 50.0 x 150.0 mm, 156 parts (43 on the bottom side), 111 nets.

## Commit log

2026-07-19 mosfet control test
2026-07-19 moved software to ODIN. added KICAD pcb design
    [ASGARD V0.1.kicad_pcb, ASGARD V0.1.kicad_sch, ASGARD.csv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]
2026-07-19 added git ignore for kicad .history folders
2026-07-20 gnss complete. only sensors left
    [ASGARD.kicad_pcb, ASGARD.kicad_sch]
2026-07-21 completed routing
    [ASGARD.kicad_pcb, ASGARD.kicad_sch]
2026-08-12 V0.2 Complete and Manufactured
    [ASGARD.kicad_pcb, ASGARD.kicad_sch]
